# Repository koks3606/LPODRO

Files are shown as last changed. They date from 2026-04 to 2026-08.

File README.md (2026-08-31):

# LPODRO

  

**A cheap, highly automated, and compact machine for home production of PCBs and finished electronic circuits.**

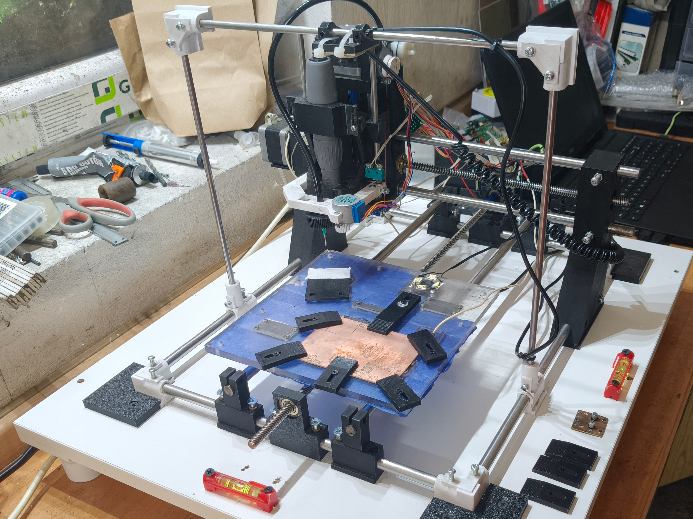
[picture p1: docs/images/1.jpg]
machine


LPODRO was designed with makers, hobbyists, amateurs, and small workshops in mind. It replaces chemical processes with precise milling of traces and holes, and its pick-and-place module automatically mounts SMD components onto the finished boards. A vision system automates calibration, inspection, and position correction of components. The project is open-source — anyone can build and modify the machine for rapid prototyping of their own circuits.

## Table of Contents

- [What it does](#what-it-does)

- [Current project status](#current-project-status)

- [Requirements](#requirements)

- [Repository structure](#repository-structure)

- [Getting started](#getting-started)

- [Machine construction](#machine-construction)

- [PnP head](#pnp-head)

- [Vision system](#vision-system)

- [Control electronics](#control-electronics)

- [Software](#software)

- [Automated circuit soldering (planned)](#automated-circuit-soldering-planned)

- [Roadmap / TODO](#roadmap--todo)

- [License](#license)

## What it does

At the core of LPODRO is a machine surrounded with a simple, automated workflow: the user supplies laminate and SMD components, and the machine carries out the successive stages of the process. The cameras determine the positions of the supplied materials and monitor every stage of production. A spindle precisely mills traces and mounting holes, eliminating the need for outdated and hazardous chemical PCB production processes and turning raw laminate into a functional PCB. The pick-and-place module then places the SMD components onto the board with high accuracy, and an integrated soldering module (to be added) will permanently bond the components to the board — so that with minimal effort and without needing extensive knowledge, the user ends up with a fully finished, working circuit.

## Current project status

> **The project is still a work in progress (WIP).**

At this point, LPODRO can reliably:

- mill single-layer PCBs,

- detect 0805 and bigger components,

- use them for automated assembly.

The 3D models, software, and other materials presented in this repository are not yet finished or fully polished. Proper documentation and many features are missing, there are known bugs and issues, and more are yet to be found.

At this point I'm not discouraging anyone to build LPODRO for yourself. Most of the features I plan to add will be done either through software or by adding stuff ontop of existing hardware. Even now LPODRO can be useful but with time it will be easier to build and have more functions. Note that right know you need some knowledge to work with LPODRO (look at [Requirements](#requirements))

## Requirements

Before starting a build, it helps to have:

- Basic knowledge of how CNC machines are built and operated — both mechanically and on the software side, later on this requirement will be removed through easier to use software.

- Basic knowledge and tools needed to solder, program MCUs and assemble hardware (cutting, grinding etc.).

## Repository structure

```
LPODRO/      
├── hardware/   STEP/STL files, schematics and technical drawings  
├── software/   Python script for the raspberry pi and main code alongside requirements.txt      
├── docs/       Assembly instructions, user manual and photos      
├── LICENSE      
└── README.md
```

## Getting started

Everything you need to get started is in the [assembly manual](docs/manuals/assembly%20manual.pdf).

## Machine construction

The mechanical construction of LPODRO is based on a frame made of steel rods joined with 3D-printed angle brackets. This solution allows for a simple and extremely cheap frame, which forms the basis of the entire machine — subsequent parts, such as motor mounts and axis holders, slide onto it. The drive system for the X, Y, and Z (spindle) axes is based on the classic mechanism of two guide rails and one T8 trapezoidal lead screw driven by a Nema17 stepper motor. The machine is equipped with two Z axes: the first moves the spindle, and the second — mounted on the spindle holder — operates the PnP head, allowing independent control of the spindle and the head and simplifying the mechanics.

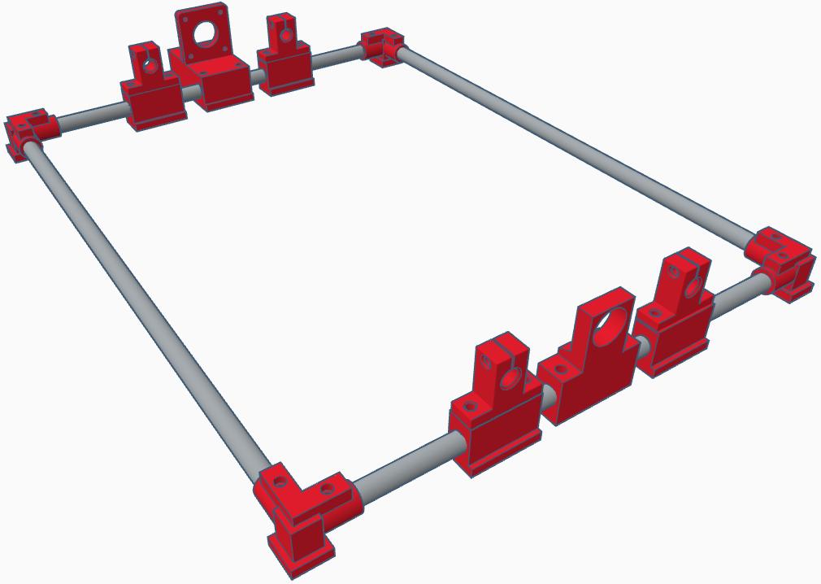
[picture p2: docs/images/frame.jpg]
frame


## PnP head

The PnP head was built from scratch for this project, using widely available and very cheap parts while retaining the functionality of commercially available equivalents. It features an easy needle-change mechanism, with needles widely available in a variety of sizes. It also has a built-in stepper motor that, working together with the vision system, rotates the picked-up components appropriately so that they land in the correct position on the PCB being produced. The head's motion system uses a non-standard, simple drive based on a wound string: the motor winds or unwinds the string, changing its effective length, which translates into the up-down movement of the head. This solution ensures low cost, simple construction, and high resistance to mechanical damage — in the event of a collision, the head will simply "bottom out" against the work surface instead of being damaged.

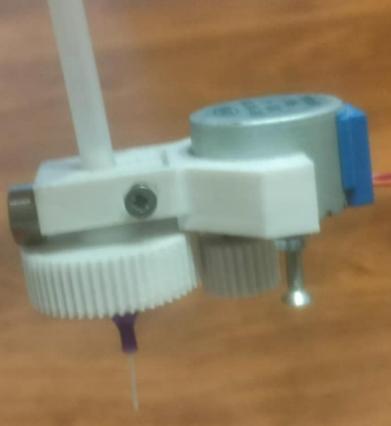
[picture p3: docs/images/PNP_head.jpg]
PNP HEAD


You can also check out the [demo](https://youtu.be/qNj2u1QFK_k).

## Vision system

A key element of the system is two cameras. A ceiling camera, positioned above the work surface, photographs the entire working area to locate the laminate, automatically determine the optimal zero point (minimizing material waste), and detect the positions of SMD components prepared by the user for mounting. A second camera is mounted flush with the work surface — the picked-up SMD component passes over the lens, and the vision system determines its orientation and offset relative to the PnP needle, allowing precise correction of rotation and position before placement. This is conceptually identical to industrial PnP equipment, but implemented in a cost-effective way.

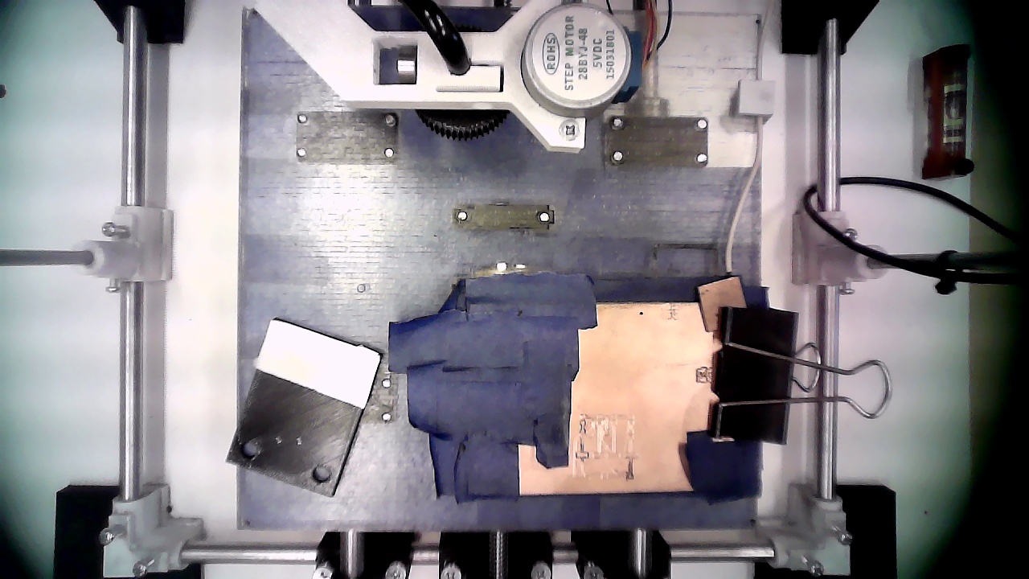
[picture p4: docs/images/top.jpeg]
top
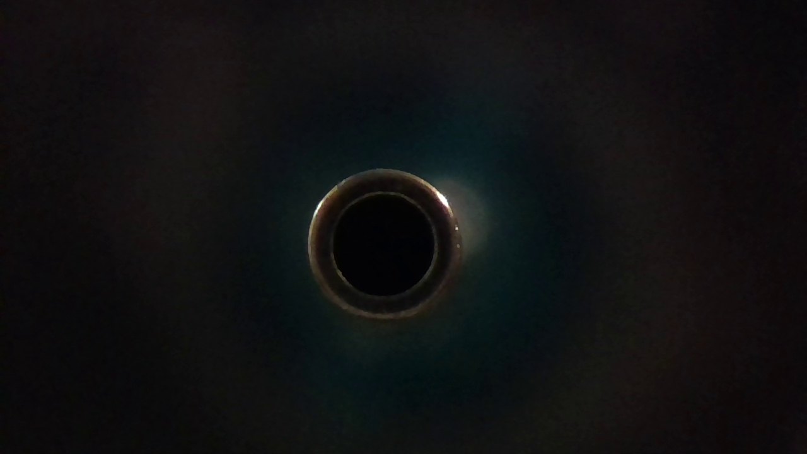
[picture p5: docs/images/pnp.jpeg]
pnp
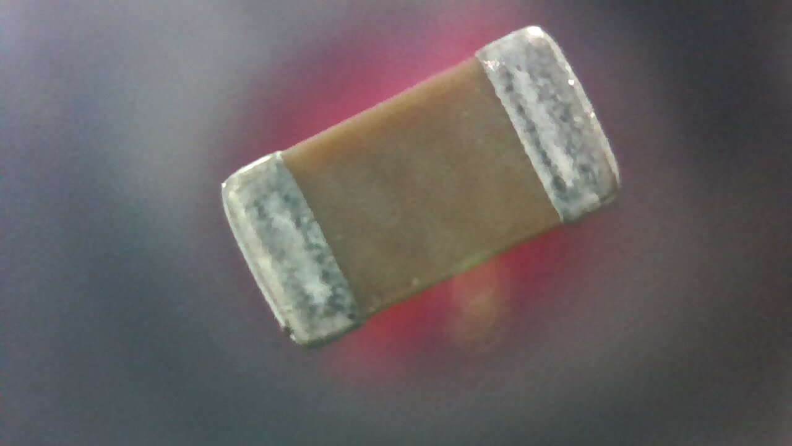
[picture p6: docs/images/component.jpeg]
component
  

## [Control electronics](hardware/schematics/Schematic.pdf).

The control electronics are based on widely available components: an Arduino Nano running GRBL firmware controls the X, Y, and Z axes using A4988 stepper drivers. A second system, a Raspberry Pi Zero W, currently controls the PnP head's stepper motors as well as the operation of the spindle, vacuum pump and LEDs. All other processes (G-code generation, auto-leveling, sending information to the machine, receiving the camera signal, etc.) currently run on a computer that must remain constantly connected to the machine. In the future, the Raspberry Pi will take over all these tasks, meaning that operating the machine will only require any device from which a PCB Gerber file and a PnP coordinate file can be sent — similar to modern 3D printers. To achieve this, the plan also includes adding a screen and buttons to the machine.

## Software

The software for LPODRO was written from scratch because available solutions (both commercial and open source) did not fully meet the required automation and usability goals. It's responsible for fully automating the process: auto-calibration, image analysis, milling toolpath generation, pick-and-place operation sequencing, position correction using camera data, and error handling and safety procedures. Currently, the user interface is CLI-based; a GUI overlay is planned for the future to significantly improve ease of use. Currently, the software supports importing popular PCB design formats, process parameterization, and job progress monitoring. All of the software is written in Python.

## Automated circuit soldering (planned)

The project plans to add an integrated heating plate to the machine, placed in the work surface. Once a board with solder paste applied is placed on it, the system will adjust the temperature profile and evenly heat the PCB to reflow temperature, enabling mass, repeatable bonding of SMD components without manual soldering of individual parts. This will significantly raise the level of automation and ergonomics, shortening operation time and reducing user interventions, and will allow the entire process of producing an electronic circuit — creating the PCB, placing components, and soldering them — to be closed within one device. Control of the heating profile (temperature sensor plus regulation) will ensure assembly safety and repeatable results across different boards and components.

## Roadmap / TODO

**Hardware**

- [ ] Improve the general experience with SMD components

- [ ] Add automated circuit soldering

- [ ] Add a way to make two-layer PCBs

- [ ] Try converting an old 3D printer into LPODRO

**Software**

- [ ] Add a way to generate stencil files (to either 3d print or mill)

- [ ] Move everything that runs on an addtional PC to the RPI

- [ ] Add a GUI to the software

**Documentation**

- [ ] Improve the manual

## License

This project is released under the [MIT License](LICENSE).

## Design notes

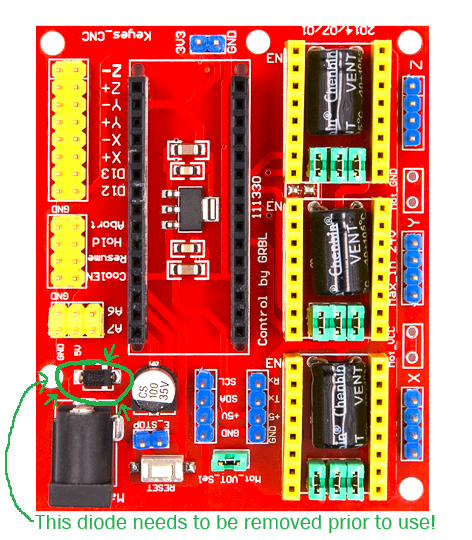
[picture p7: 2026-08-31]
hardware/schematics/Diode.png

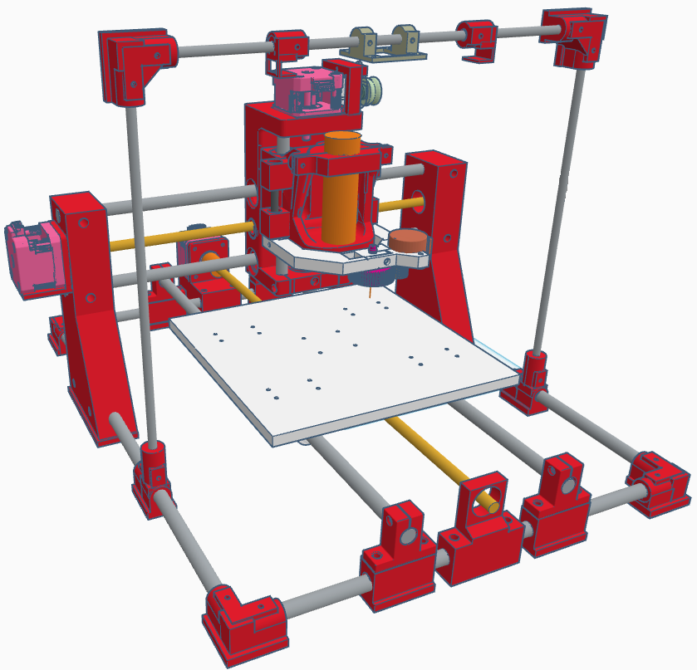
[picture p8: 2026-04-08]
hardware/STLs/3d visualization.png

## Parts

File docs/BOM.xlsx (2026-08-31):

Nb | name | quantity | notes | example link
1 | filament | ~1kg | do not use PLA! Use PETG or something stronger | link (https://allegro.pl/oferta/filament-sunlu-petg-black-czarny-1kg-1-75mm-18720979372)
2 | 10mm steel rod | 334cm | 2x 41cm and 2x 31.5cm for the frame, 2x 44cm for the y axis, 2x 36.5cm for the x axis and 2x 14cm for the z axis | buy localy
3 | 6mm steel rod | 121cm | 2x 28.5cm and 32cm for the camera frame and 2x 16cm for the second z axis
4 | 500mm T8 screw | 1 | can either have 2mm or 8mm pitch, can be cut down to 45cm to not stick out | link (https://abc-rc.pl/pl/products/sruba-trapezowa-t8x8-500mm-nakretka-z-brazu-thsl-500-8d-8606.html?query_id=1)
5 | 400mm T8 screw | 1 | can either have 2mm or 8mm pitch, can be cut down to 36.5cm to not stick out | link (https://abc-rc.pl/pl/products/sruba-trapezowa-t8x8-400mm-nakretka-z-brazu-thsl-400-8d-8605.html?query_id=1)
6 | 250mm T8 screw | 1 | can either have 2mm or 8mm pitch, needs to be cut down to 13cm to not stick out | link (https://abc-rc.pl/pl/products/sruba-trapezowa-t8x8-250mm-nakretka-z-brazu-thsl-300-8d-20284.html?query_id=1)
7 | sd card | 1 | at least 16gb | link (https://elektroniksc.com.pl/technika-komputerowa/karta-pamieci-micro-sd-hc-16gb-adapter-sd-goodram-66-240-rohs/)
8 | 685zz bearing | 1 |  | link (https://allegro.pl/oferta/685-zz-lozysko-wysokoobrotowe-5x11x5-mm-618-5-zz-2z-6521264095)
9 | 608zz bearings | 3 |  | link (https://abc-rc.pl/pl/products/lozysko-kulkowe-8x22x7-os-8mm-typ-608zz-8496.html?query_id=3)
10 | nema17 steppers | 3 | can be basically any nema17 motor, I used 17pm-k343cn03ca ones. New ones can be bought but they are VERY expensive for some odd reason. Check locally for used ones. | link (https://elektroniksc.com.pl/silniki-elektryczne-dc/silnik-dc-2-fazowy-krokowy-bipolarny-nema17-3-4v-dc-1-7a-krok-1-8-200-krokow-na-obrot-4-28kg-cm-0-42nm-wale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)
11 | 8mm to 5mm couplers | 3 | use the rigid ones, not the flexible ones used in, for example, 3d printers z axies | link (https://botland.com.pl/elementy-do-budowy-drukarek-3d/18933-sprzeglo-stale-aluminiowe-5x8mm-5904422355012.html)
12 | lm10uu bearings | 8 or 12 | the quantity depends on how many you will put in the z axis and spindle carraiges | link (https://abc-rc.pl/pl/products/lozysko-liniowe-lm10uu-10mm-reprap-3d-cnc-9734.html?query_id=13)
13 | lm6uu bearings | 4 |  | link (https://allegro.pl/oferta/lm-06-uu-lozysko-liniowe-na-walek-6mm-lm6uu-17576690130)
14 | T8 nuts | 6 | T8 screws often come bundled with at least one T8 nut. Buy nuts with the same pitch as the screws | link (https://abc-rc.pl/pl/products/nakretka-t8x8-z-brazu-do-sruby-trapezowej-4-zwoje-drukarka-3d-9275.html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)
15 | ov9726 camera | 1 | the bed camera, use with lens from the second camera | link (https://pl.aliexpress.com/item/1005003808666298.html)
16 | the second camera | 1 | this one doesnt really have any markings lol, use it with the bed camera lens | link (https://pl.aliexpress.com/item/1005004542714669.html)
17 | bed leds | 4 | can be any bright, white, smd leds. | link (https://elektroniksc.com.pl/diody-led-smd/dioda-led-e2-stw8q14d-smd-5630-biala-4000k-bialy-31-2lm-2-7-2-8v-65ma-120-seoul-semiconductor-s1w0-5630xx8003-000000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)
18 | the bed | 1 | Personally i ordered one from 8mm pmma but i would recommend making it out of 4mm steel | link (https://allegro.pl/oferta/blacha-stalowa-formatka-25x25-cm-stal-4mm-12075468236)
19 | 28byj-48 stepper | 2 |  | link (https://abc-rc.pl/pl/products/silnik-krokowy-28byj-48-z-przekladnia-5v-0-3a-0-03nm-arduino-6290.html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)
20 | 6x4mm tube | ~40cm | cut it down during assembly | link (https://abc-rc.pl/pl/products/wezyk-do-kroplownikow-4-6-mm-waz-kapilarny-pcv-do-nawadniania-mikrozraszaczy-17616.html)
21 | string | ~40cm | I just used some sewing string i stole from my mom
22 | Marathon sde-h37ln | 1 | this is the spindle itself, I personally used this exact model but on for example aliexpress there are cheaper alternatives, haven’t tried them tho | link (https://pl.aliexpress.com/item/1005007485295420.html)
23 | milling bits | a lot | you’ll most likely break a lot of bits during the early phase of using LPODRO. Marathon is a great spindle but it only can use bit that have a ~2mm handle. I bought this kit and it has 3 bits that can actually be used for milling pcbs. Buy at least 2 sets | link (https://pl.aliexpress.com/item/1005007243870497.html)
24 | vacuum pump | 1 | do note that this pump is a consumable – it will break over time, I recommend buying at least two | link (https://pl.aliexpress.com/item/1005008684218965.html)
25 | m3 screw | a lot | its best to buy a set of different lengths | buy localy
26 | m3 nuts | a lot
27 | Mains cable | 1 |  | link (https://elektroniksc.com.pl/kable-zasilajace-1/kabel-zasilajacy-wtyk-cee-7-7-prosty-przewody-16a-250v-1-8m-czarny-3-zyly-1-5mm2-pvc-okragly-linka-cu-lian-dung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)
28 | female DIN connector | 1 | Either a 3 or 5 pin can be used. If you are using a spindle other then the marathon one check if its using this connector | link (https://elektroniksc.com.pl/zlacza-din-i-glosnikowe/gniazdo-din-zenskie-5-pin-uklad-wypr-180-proste-lutowane-dc-102/)
29 | Theraded heat inserts | 38 |  | link (https://allegro.pl/oferta/mosiezna-wkladka-gwintowana-insert-niska-m3-x-4mm-100-szt-18782797301)
parts from the schematic
30 | uln2003 driver | 2 | do note that they have a tendency to randomly die. Buy at least 4 | link (https://abc-rc.pl/pl/products/modul-sterownika-uln2003-v2-do-silnikow-krokowych-arduino-6405.html?text=uln2003)
31 | Limit switches | 4 | i used a wk325 switches | link (https://elektroniksc.com.pl/mikroprzelaczniki-snap-action/mikroprzelacznik-wk325-dzwignia-13mm-1no-1nc-mini-1a-125v-ac-kw10-z2p150-msw-22-kls-rohs/)
32 | raspberry pi zero w | 1 |  | link
33 | Relay | 3 | 5v coil voltage, >24v contact voltage. Arduino relay modules can be used and that will eliminate the need for the whole relay circuitry | link (https://elektroniksc.com.pl/przekazniki-bistabilne/przekaznik-tq2-l2-5v-bistabilny-5v-dc-dpdt-2-styki-przelaczne-2-cewki-0-5a-125v-na-pcb-az850p2-5-panasonic-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) | link (https://elektroniksc.com.pl/moduly-przekaznikow/modul-rozszerzeniowy-4-przekaznik-5v-dc-z-separacja-optyczna-10a-250v-kolkowe-srubowy-4-kanaly-arduino-iot-diy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)
34 | Diode | 3 | Any diode can be used. It's used to discharge the negative voltage spike from the relay coils. For example 1N4007 can be used | link (https://elektroniksc.com.pl/diody-prostownicze/dioda-prostownicza-1a-1000v-1kv-do41-tht-1n4007-rohs-opakownaie-100szt/)
35 | NPN transistor | 3 | Used to drive the relay. 2N2222 can be used. | link (https://elektroniksc.com.pl/tranzystory-npn/tranzystor-2n2222-npn-0-6a-40v-625mw-250mhz-to92-tht-0743-ph2222a-pn2222-rohs-op-100szt/)
36 | Transistor resistor | 3 | The resistor on the transistor base. I used a 680ohm one | link (https://elektroniksc.com.pl/rezystory-0-125-0-5w/rezystor-weglowy-680ohm-0-25w-1-4w-5-0207-tht-cf1-4w-680r-rohs-opakowanie-100szt/)
37 | LED resistor | 1 | The resistor before the LEDS. Heavily depends on the type and amount of LEDs you choose. I used an 680ohm one | link (https://elektroniksc.com.pl/rezystory-0-125-0-5w/rezystor-weglowy-680ohm-0-25w-1-4w-5-0207-tht-cf1-4w-680r-rohs-opakowanie-100szt/)
38 | CNC shield v4 | 1 | Check this out as this is very important (https://www.instructables.com/Fix-Cloned-Arduino-NANO-CNC-Shield/) | link (https://abc-rc.pl/pl/products/modul-do-grawerowania-cnc-v4-shield-do-arduino-nano-9470.html)
39 | 24v psu | 1 | i used a 150w one. You may want to calculate the power on your own based on the steppers you chose | link (https://allegro.pl/oferta/zasilacz-do-tasm-led-24v-dc-6a-150w-slim-modulowy-transformator-montazowy-13380444696)
40 | 12v source | 1 | I used a small 230vac to 12vdc psu. A step down buck can be used but then you may need to use a more powerful 24psu | link (https://elektroniksc.com.pl/moduly-przetwornic/przetwornica-step-down-ac-dc-csc7203-uwej-230v-uwyj-12v-prad-1a-12w-43x25mm-a-pn-1a-dc-jh/)
41 | 5v source | 1 | I used a small 230vac to 5vdc psu. A step down buck can be used but then you may need to use a more powerful 24psu | link (https://elektroniksc.com.pl/przetwornice-regulatory/przetwornica-step-down-ac-dc-uwej-230v-uwyj-5v-prad-2a-10w-43x25mm-a-pn-10w-jh/)
42 | alligator clip | 1 | This is the probe that is placed on the mill when probing the z height and doing the autoleveling | link (https://elektroniksc.com.pl/krokodylki-pomiarowe/krokodylek-izolowany-41-5mm-czerwony-nh041-zaciskany-stal-niklowana-27-711-1-amass-rohs-opakowanie-100szt/)
3d printed parts
43 | Gear 1 | 1
44 | gear 2 | 1
45 | Y axis rod holder | 4
46 | Second Z axis spool | 1
47 | PnP head frame | 1
48 | X axis pillar 1 | 1
49 | X axis pillar 2 | 1
50 | Spindle clamp | 1
51 | Bed bearings | 4
52 | Y axis bearing holder | 1
53 | Bed nut 1 | 1
54 | Bed nut 2 | 1
55 | Second Z axis stepeper holder | 1
56 | Z axis carriage | 1
57 | Camera frame connector | 2
58 | Y axis stepper holder | 1
59 | angle connector | 6
60 | Spindle carriage | 1 | either the completed one or not, if not also print the second Z axis bearing holders
61 | Camera holder | 1 | either the camera holder itself or phone holder 1 and 2 if you are using a phone
62 | pcb holder | depends | depends on how big laimantes you're going to mill

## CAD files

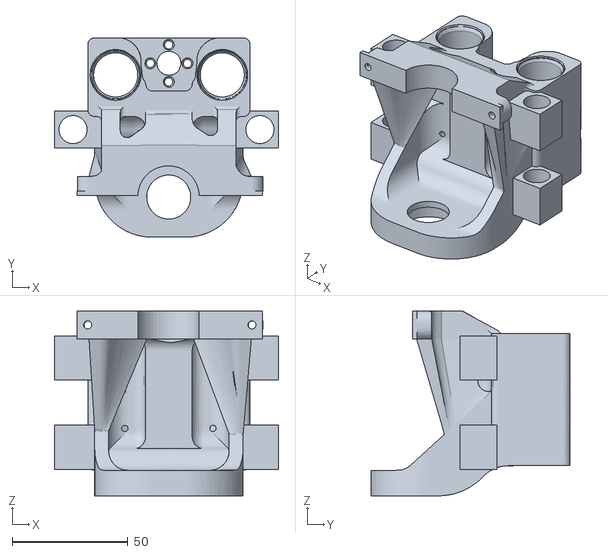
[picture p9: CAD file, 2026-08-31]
hardware/STLs/complete spindle carriage.stl
96.6 x 86.0 x 79.6

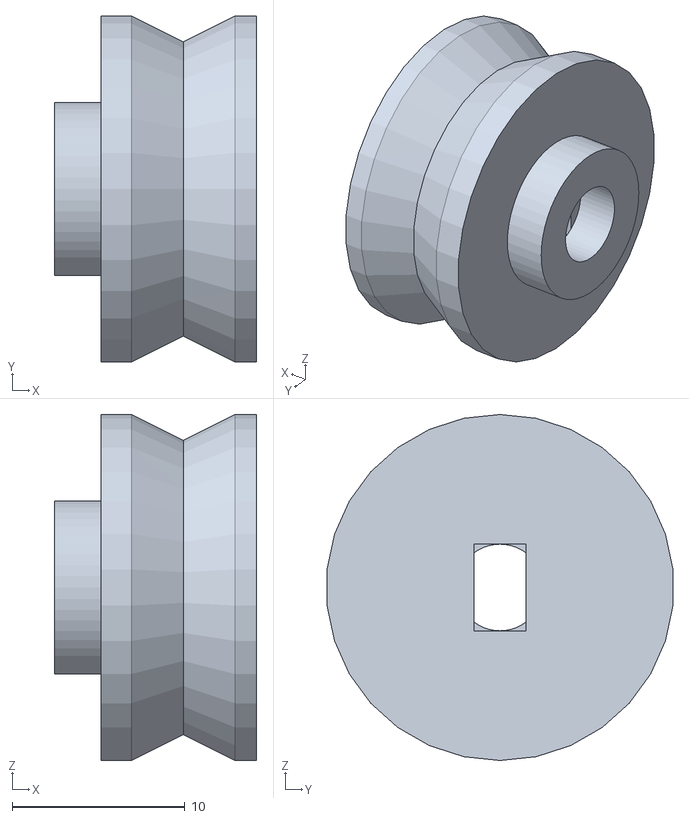
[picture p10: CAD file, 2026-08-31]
hardware/STLs/second Z axis spool.stl
11.7 x 20.0 x 20.0

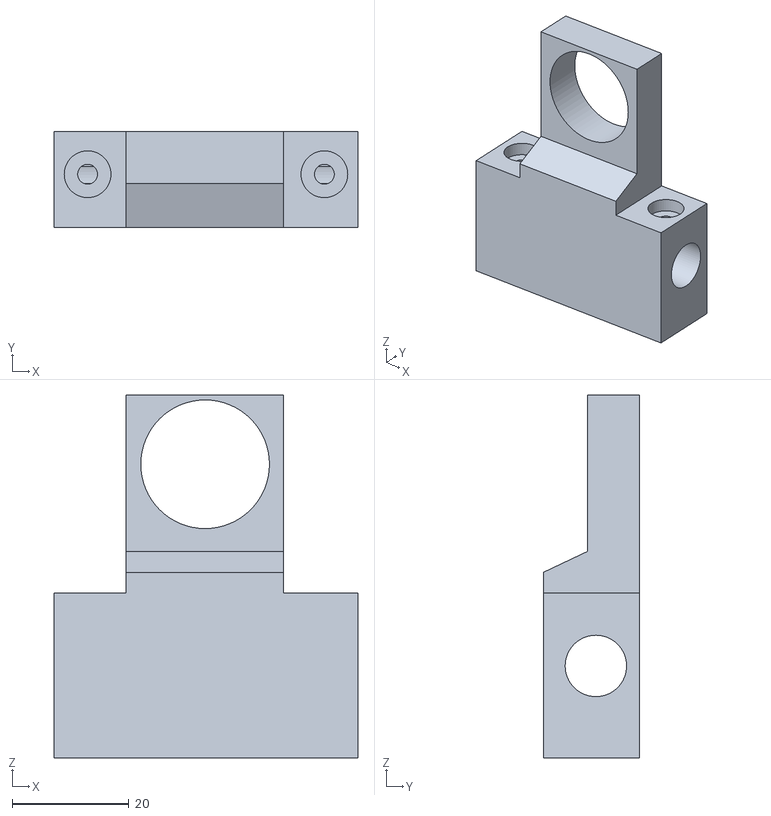
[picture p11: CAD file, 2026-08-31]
hardware/STLs/Y axis bearing holder.stl
52.0 x 16.5 x 62.1

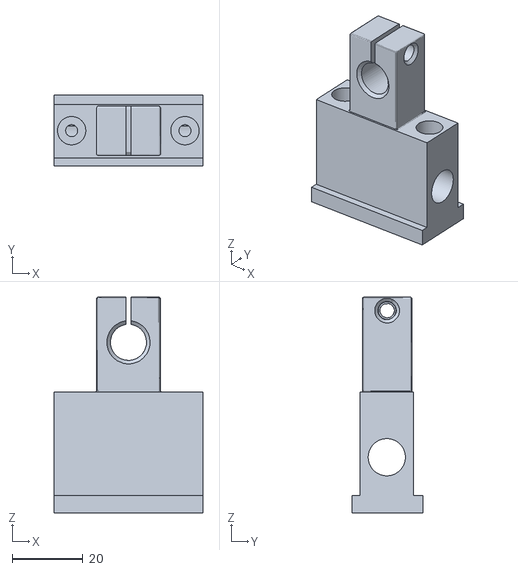
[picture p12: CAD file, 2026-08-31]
hardware/STLs/Y axis rod holder.stl
42.0 x 20.0 x 61.0

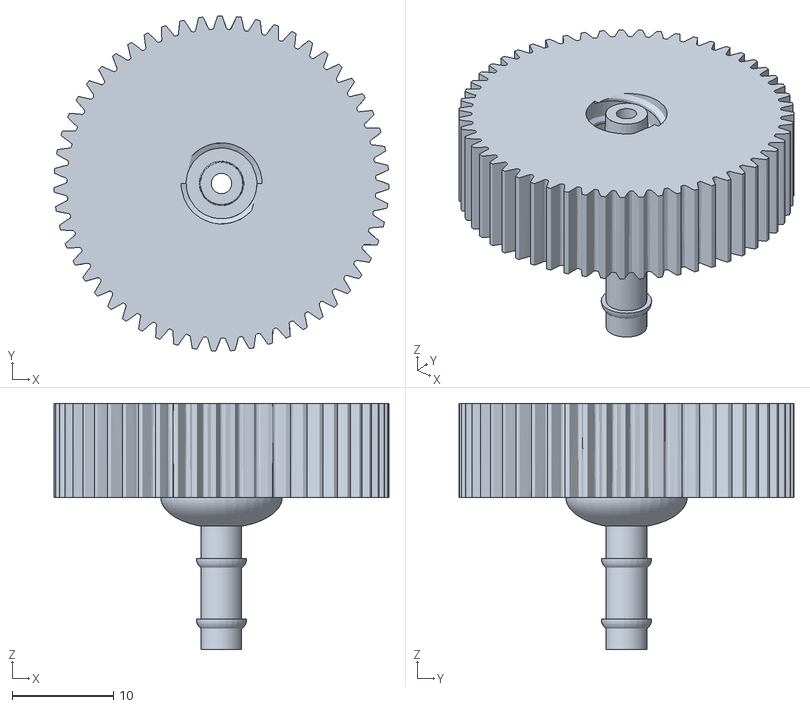
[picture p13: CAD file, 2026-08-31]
hardware/STLs/gear 1.stl
33.1 x 33.0 x 24.3

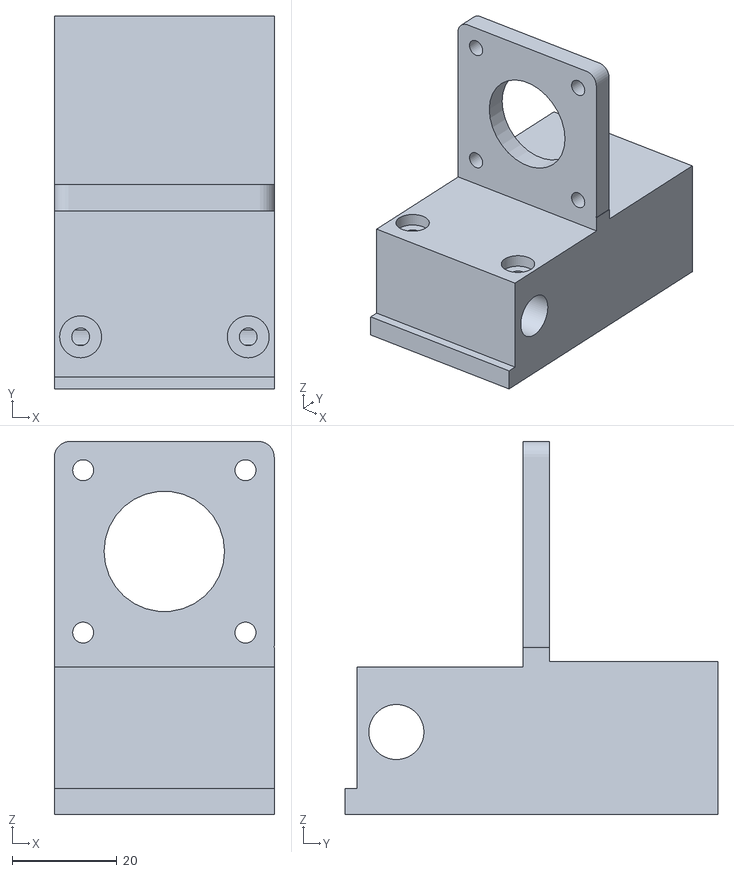
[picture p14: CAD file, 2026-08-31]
hardware/STLs/Y axis stepper holder.stl
42.1 x 71.2 x 71.2

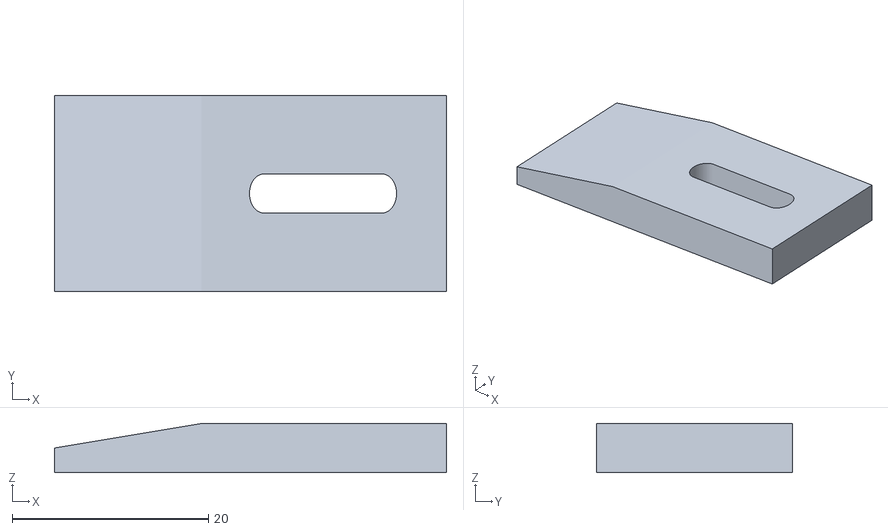
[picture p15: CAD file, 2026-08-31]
hardware/STLs/pcb holder.stl
40.0 x 20.0 x 5.00

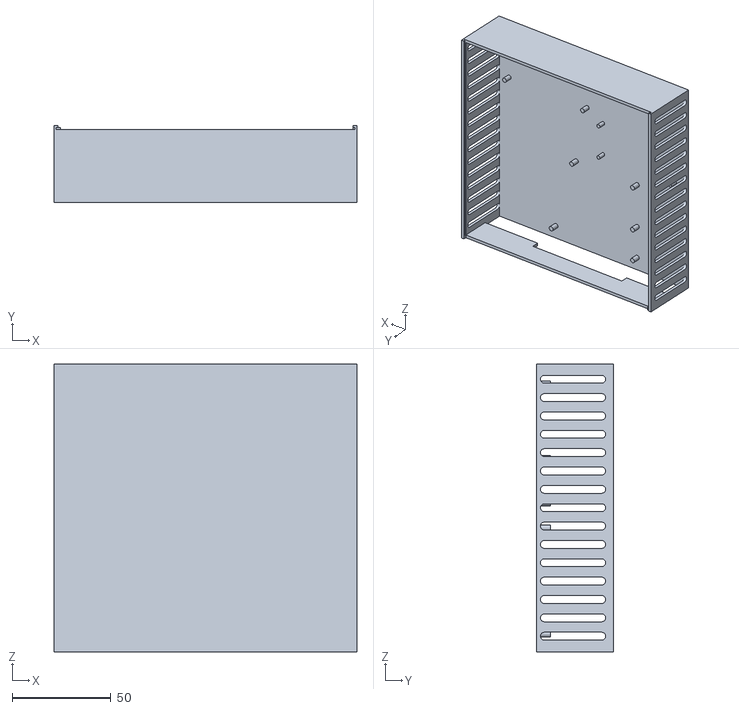
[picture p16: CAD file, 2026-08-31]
hardware/STLs/case.stl
153.3 x 39.0 x 145.7

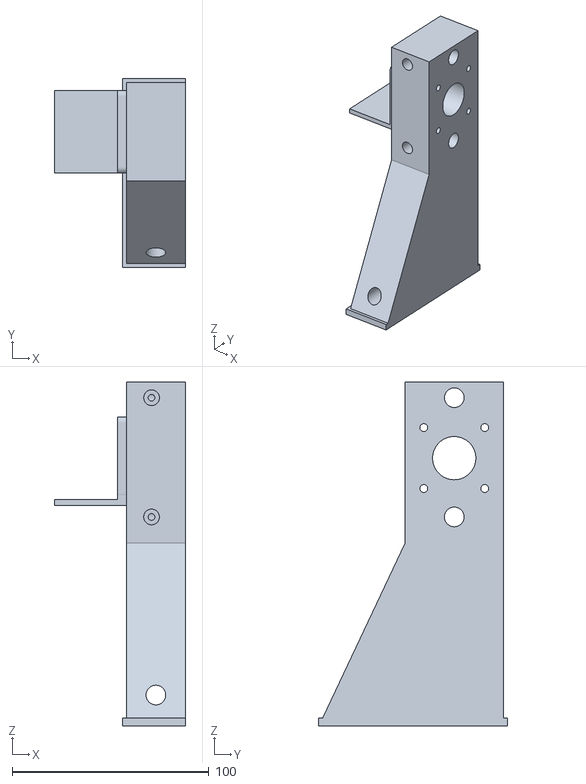
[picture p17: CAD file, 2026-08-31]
hardware/STLs/X axis pillar 1.stl
66.7 x 96.0 x 175.0

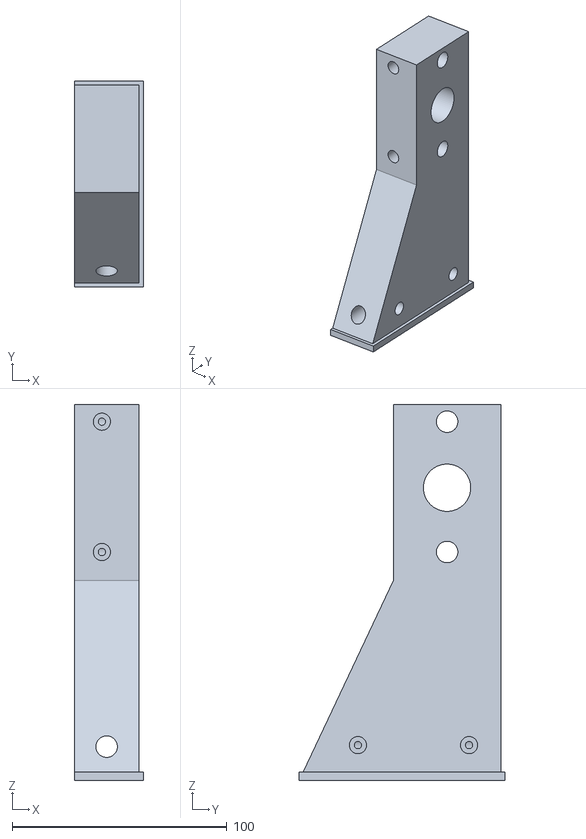
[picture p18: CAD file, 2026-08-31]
hardware/STLs/X axis pillar 2.stl
32.0 x 96.0 x 175.0

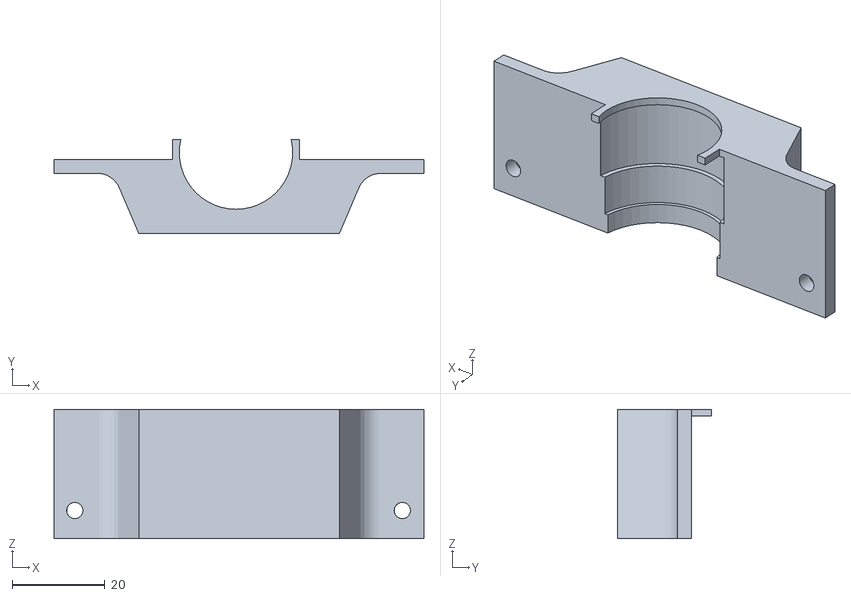
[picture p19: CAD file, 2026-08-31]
hardware/STLs/spindle clamp.stl
80.0 x 20.4 x 28.0

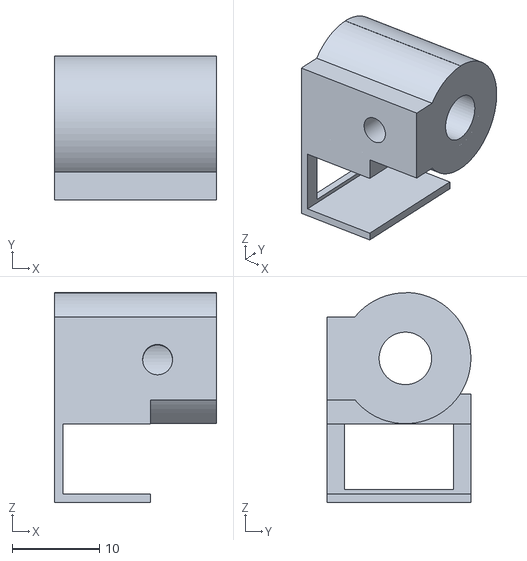
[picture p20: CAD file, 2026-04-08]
hardware/STLs/phone holder 1.stl
18.5 x 16.5 x 24.0

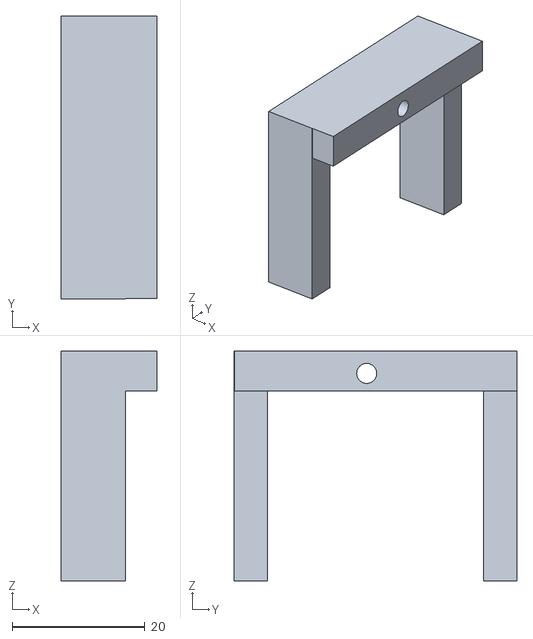
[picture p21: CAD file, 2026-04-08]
hardware/STLs/second Z axis stepper holder.stl
14.4 x 42.6 x 34.6

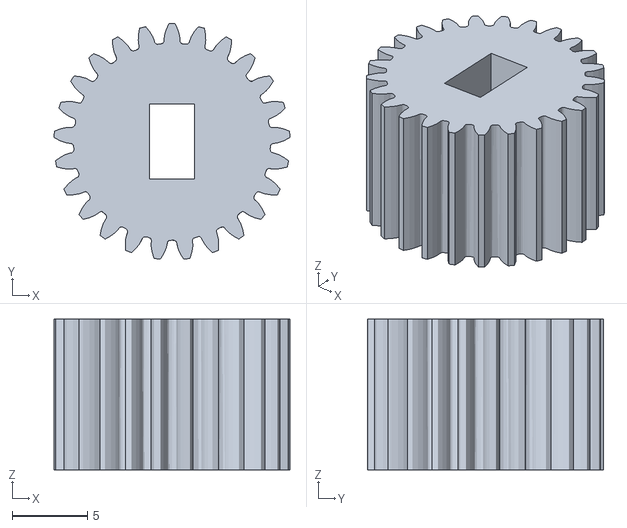
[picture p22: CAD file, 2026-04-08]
hardware/STLs/Gear 2.stl
15.6 x 15.6 x 10.0

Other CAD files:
hardware/drawings/bed.FCStd
hardware/STLs/spindle carriage.stl
hardware/STLs/angle connector.stl
hardware/STLs/camera holder.stl
hardware/STLs/PnP head frame.stl
hardware/STLs/Z axies carriage.stl
hardware/STLs/bed bearing.stl
hardware/STLs/bed nut 1.stl
hardware/STLs/bed nut 2.stl
hardware/STLs/camera frame connector.stl
hardware/STLs/phone holder 2.stl
hardware/STLs/second Z axis bearing holders.stl

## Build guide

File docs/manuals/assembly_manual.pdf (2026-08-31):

# About This Manual

In this manual I’d like to create a step-by-step tutorial that will guide you through building your own LPODRO machine.
This is the first version of this manual that is still a WIP. In the future I’d like it to be in a easy to read form, with a lot of pictures that will show what exactly you need to do. I also plan to record a video tutorial to further simplify the building process.
As of right now the current state of this manual is more like an info dump by me – sharing everything I learned over the past 3 years while working on this project. Most likely I will skip or forget something here, that's why in the readme file it says that you need to have at least some knowledge of how CNC machines are built. At this point it is more than likely that you will need to figure out some stuff out on your own.

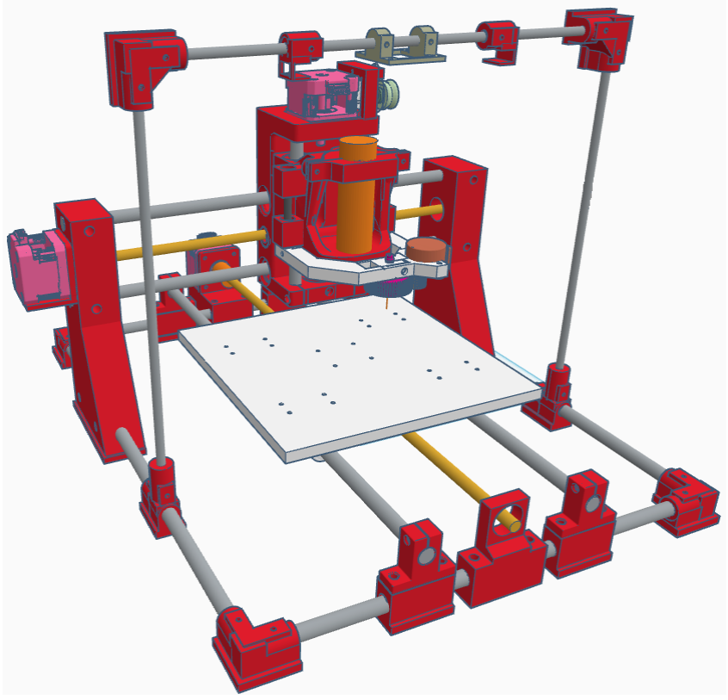
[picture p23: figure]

This is the visualization picture. While following this manual keep in mind that this ^ is what you are building. Each step will get you closer to having this machine. After each step check if whatever you did looks like what is on this picture. If not you most likely did something wrong.

# Frame Assembly

Step 1: Cut the rods to length
To start out the building process you need to cut the 10mm rod into the proper lengths: 2x 41cm and 2x 31.5cm for the main frame, 2x 44cm for the y axis, 2x 36.5cm for the x axis and 2x 14cm for the z axis. For this I used an angle grinder. I also used it to round out the rough edges. Be aware that the rods will get very hot – don’t touch them and don’t put them into the 3d printed parts right after cutting them.

Step 2: Check the 3D printed parts fit the rods
After cutting the rod, take the ones that will be used for building the main frame alongside 4 angle connectors, both X axis pillars, 4 Y axis rod holders, Y axis bearing holder, Y axis stepper holder and 2 camera frame holders. Take the 3d printed parts and check if the hole that the rods will go into have the proper diameter. To do so take a rod and try inserting it into the hole. There shouldn’t be to much resistance (if you put too much pressure the part will just split open on the layer lines) but also the rod cannot be extremely loose. It should go in with just a bit of pressure and have a bit of give in each direction. If it doesn’t either drill the hole out to a proper size or file it down. Now you need to make a choice because you can either put threaded inserts into the 3d printed parts or screw a screw right into it. Personally I did the latter because it’s much simpler and it’s strong enough for what you’re doing here. But if you insist on using threaded inserts the tip I can give you is after melting it in wait a bit to let the molten plastic harden. When it does take something thin, that can be inserted into the threaded insert without touching the threads, put it as far as you can and hit it pretty hard with your hand or a hammer. This will break out the plastic that has molten into the part that the rod will go into. If you don’t do this you won’t be able to screw the screw or put the rod in. If you choose to screw into the parts you need to do this at least once before putting the rod in.
Step 3: Insert the rods into the connectors
Next, take the two shorter rods, insert the Y axis rod holder, Y axis bearing holder and again a Y axis rod holder onto the first and and Y axis rod holder, Y axis stepper holder and again a Y axis rod holder on the second one. Insert each of the X axis pillars and camera frame connectors onto the longer rods.
Step 4: Form and square the main frame
After that insert the prepared rods into the angle connectors to form the main frame with inserted components in such a way that each part is orientated as shown on the visualization picture.
If what you have looks similarly to the visualization picture take 8 screws and put them into the angle connectors in such a way that they won’t fall out but wont stop the rod from moving freely in the connectors. Now you need to tighten the screws but also at the same time make sure that the rods form a right angle with each other to get a square frame. To do so you need to grab a machinist's square, put it in such a way that one of it arms goes parallel to one rod and the second one with a second and when the rods form a right angle tighten the screw. Repeat this process for all corners.

# Bed Assembly

Step 5: Prepare the bed plate and nut holders
With that done the next step is preparing the bed. Personally I ordered it to be cut out from PMMA but if not for the fact that I already had a PMMA sheet lying around that would have been very expensive. What I recommend doing is to buy a 25x25cm, 4mm thick steel sheet, drill the holes and make the camera cutout according to the bed.svg drawing and tap the holes with an m3 thread. Next take 4 bed bearing holders and both nut holders. Take the first T8 nut and screw it completely into the holder with holes. The second T8 nut goes into the holder with slots, put the 4 screws in, screw the m3 nuts onto them but don't tighten them – the nut needs to turn freely for now. Next take the bearings and push them into the holders. It should require a lot of force so they don’t fall out during normal operation but if you see any cracks forming on the holders during this step, replace the cracked part with a new one and file everything down a bit. After inserting the bearings make sure that one side is absolutely flush with its holder. It cannot be crooked or anything like that.
Important: Pay EXTRA attention to the bearings being flush with their holders – I wasted literal days trying to fix my machine only to find out I installed one of the bearings at an angle.

With that finished, take the bed and the prepared holders and screw them together. Make sure that the screws don’t poke out on the other side of the bed. If they do, add a nut or a washer to the screws.

Step 6: Mount the bed camera
As the last step take the bed camera (the ov9726 one with the lens from the second one), place it under the bed so that the lens points up and screw it in from the top.
Checkpoint: You should have a fully assembled bed with one loose T8 nut.

# Y Axis Assembly

Step 7: Prepare the Y axis stepper motor and bearing
Now you can take the Y axis stepper motor, a coupler and a T8 screw. Put the coupler onto the motor shaft and screw it in in such a way that one of the coupler screws pushes onto the flat part of the shaft. Next take the T8 screw, put it in the coupler and slowly tighten one of the coupler screws while rotating the T8 screw – the goal of this is to screw the coupler screw into the thread of the T8 screw. You will feel it when you hit the right spot. When you do it, tighten that coupler screw fully and then the second one and put this contraption aside. Now take the 608zz bearing and install it into the Y axis bearing holder.
Step 8: Slide the bed onto the Y axis rods
After that take the Y axis rods and put them through the first holder but not the second – leave the ends of the rods floating approximately in the middle, then with one hand hold the ends of the rods that are outside the main frame and with the second one pick up the bed and slide it onto the rods so that it will be inside the main frame. After that slide the rods fully in so that they go into the second rod holders.
Checkpoint: You should have the main frame with a bed that can freely slide back and forth and be moved on the frame.
Step 9: Install the Y axis motor and center the bed
Now take the stepper motor with the T8 screw, put the screw through the Y axis motor mount and push it until the screws tip touches the first nut. When it does start turning the screw so that it screws into the first nut. Do it until the tip of the T8 screw reaches the second, loose nut. When it does you’ll most likely need to turn the nut a bit to let the screw screw into it. When it does turn the screw until the stepper motor touches the Y axis motor mount and the tip of the T8 screw goes through the Y axis bearing. With that done you can screw the motor to its mount and tighten the rod mounts. After that we need to make sure that the bed is centered before screwing all of its mounts to the frame. To do so turn the T8 screw manually until the bed reaches one of the ends of the frame, then take some sort of measuring device and measure the distance between the rod holders and the frame rods. If the distances are not equal, move the holders a bit and repeat the process until they are. When they are equal, tighten the screw on the two holders on the side on which the bed is, then move the middle component (either the bearing or the stepper mount) and see if it springs back to a certain place (should be the middle between both rod holders), if it does, screw it in, if it doesn’t manually place it in the middle and then screw it in. After that manually move the bed to the other side and repeat this process. After that's done make sure that when rotating the T8 screw manually the resistance you feel is equal along the whole length. If it doesn’t it means that something isn’t parallel to each other. Check the rod holder, stepper and bearing mounts distance to each other and the frame and also if the rods and the T8 screw you installed isn’t bend. Now you need to properly tighten the loose T8 nut. What you are trying to achieve is to eliminate any play in the bed movement without adding any additional resistance for the stepper motor. To do so, grab both sides of the bed with your hands and try moving it left and right (in the direction of the rods and T8 screw). The nut should be held tight in its holder that it shouldn't move on its own. If you feel a bit of give caused by improper thread spacing (what we are trying to eliminate right now), and not because something else is moving (the frame, stepper mount, the loose nut in its holder etc), turn the nut a bit and try again. When the give stops try manually turning the T8 screw. If you feel a lot of additional resistance it means that you turned the nut too much. Now you need to find an angle where the bed doesn’t have any give but also when turning the T8 screw you don’t feel any additional resistance.

When you find this point screw the 4 screw on the nut all the way in.

### Checkpoint: You should have the main frame with a bed that should smoothly move back and

forth when rotating the T8 screw but should not move at all in any direction when pushing on the bed itself.

# PnP Head Assembly

Step 10: Assemble the PnP head
Now you are going to assemble the PnP head as it will make the next step easier. To do so take the PnP head frame, gear 1 and gear 2. Then insert 3 m3 nuts into the PnP head frame - two in the designated cuts next to the rod holes and one in the cut next to the gear 1 hole. Next take the 28byj-48 stepper motor and push the gear 2 onto its shaft. After that put it in the PnP head frame and screw it in. Next take the bearing and push it onto its place. With that done push the clear tube through the top of the PnP head frame. From the bottom push the gear 1 into the tube and then pull the tube back so that the part of the gear 1 that is in it goes through the hole of the PnP head frame. With that placed correctly take an m3 screw and screw it in the hole next to the gear 1. Tighten it until the tube and gear 1 connection is airtight but don’t over do it so that the stepper motor can still rotate the gear 1. Next take the properly cut rods, insert them into the their holes, make sure they form right angles with the PnP head frame and tighten the screws.

# Spindle Carriage Assembly

Step 11: Glue the Z axis bearing holders (if using the standalone carriage)
Now you’re going to assemble the spindle carriage. To do so you can either use the stand alone spindle carriage and glue the Z axis bearing holders onto it or the complete spindle carriage. Personally I chose the first option because it was simpler to print and more forgiving on my not so good 3d printer tolerances. But what you choose is completely up to you - the complete carriage has the advantage of not needing any gluing. If you choose to glue the bearing holders onto the carriage the PnP head that you just assembled is going to help you. To do it push the bearings into the holders (remember, they need to be PERFECTLY flush!) then slide them onto the rods of the PnP head, then apply a bit of super glue onto the contact area of the bearing holders and slide them into the proper height. You need to do bearings from both sides at the same time. While doing so make sure that the rod goes parallel with the spindle carriage and that it’s not crooked. When the glue dries a bit you can glue the remaining two bearing holders.
Step 12: Install bearings, T8 nut, and fit the spindle
Next take the spindle carriage (either the complete one or the glued one) and push 2 or 4 bearings into the bearing holes (once again its VERY IMPORTANT that they are COMPLETELY flat). I recommend using 4 for better stability and longevity. Next push one T8 nut and screw it in completely on one side and on the other side do the same eliminating the play trick you used on the bed. The last step with the spindle carriage is to sand down the part that actually touches the spindle. To do so take the spindle clamp and the spindle itself. Unscrew the top cap of the spindle and push the spindle clamp onto it then screw the cap back on. Then put the spindle with the clamp into the carriage and screw the two screws completely in. From the front the spindle should go completely down, if its at an angle somethings really wrong - most likely the 3d print quality is bad (take note of that as this can cause A LOT of different problems). From the side tho it will most likely be at an angle - that is to be expected. If it is look from the top, maybe shine a light from the bottom. You’re trying to see what parts actually touch the spindle. When you do find them take the spindle out, sand those parts a bit, put the spindle back in and check from the side if it points straight down. If it doesn't repeat this process until it does.
Checkpoint: When it finally does, congrats – you have a finished spindle carriage.

# Z Axis and X Axis Assembly

Step 13: Build the Z axis carriage
With the finished spindle carriage we can assemble the X axis. To do so take the Z axis carriage and the second Z axis stepper holder and spool. Insert either 2 or 4 bearings into the Z axis carriage (once again they need to be PERFECTLY flush and straight) and two T8 nuts and do the eliminating the play thing - just like with the spindle carriage. Next push a bearing into the bottom part of the Z axis carriage. Next take a Nema17 stepper motor and install a coupler and a T8 screw just like you did with the Y axis. Then insert it through the top of the z axis carriage until the tip of the T8 screw goes into the bearing. The face of the nema17 has to be flush with its designated place on the z axis carriage. If it isn’t because the T8 screw is slightly longer you can drill a hole under the bearing but be aware that the T8 screw cant poke under the Z axis carriage. If the motor sits flush with the z axis carriage and the T8 screw doesn’t stick out of the bottom you can slightly rise the nema17 until you can put the spindle carriage under the tip of the T8 screw. Next screw the screw into the spindle carriage. With that done screw the nema 17 into the Z axis carriage. Next push two rods in and make sure they go into the holes on the top of the Z axis carriage. After that make sure that they don't poke out from the bottom. If they don’t you can screw an m3 screw into their designated spots (no nut here, it screws into the 3d print itself). That should lock the rods in place.
Step 14: Attach the second Z axis stepper, pump, and string spool

The next step would be to glue the second Z axis stepper holder and the onto the top the Z axis car-

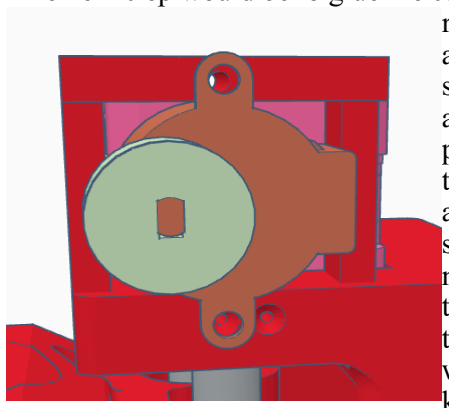
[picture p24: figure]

riage. To do so take a 28byj-48 stepper and push the second Z axis spool onto its shaft. Then insert the motor into the holder as shown on the picture, screw it together, place it on top of the z axis carriage and screw the second screw to it. With that done put some super glue along side the edge of the connection between the Z axis carriage and the second Z axis stepper holder and let it dry. To glue to pump in place just place it where it should be and put a lot of hotglue there. When it dries off connect the tube from the PnP head to the pump. To finish everything off take a piece of string, put a small dab of super glue in the middle of the spool, put the end of the string into that dab, wait for it to dry, when it does spool some string onto it, then take the string down and cut it so that it can reach to the bottom position of the pnp head (if the pnp head isn't inserted into the spindle holder that's a good time to do it). Then tie that end of the string onto the screw that is tightening the rod that's closer to the spooled stepper to the pnp head frame. With that done turn the spooled stepper so that the pnp head goes as far as it can, take a limit switch, push it into the pnp head until it clicks, then push it a bit more and glue it to one of the second Z axis bottom bearing holders.
Checkpoint: You should have a complete carriage that holds the spindle, PnP head and the pressure pump that will now go onto the X axis.
Step 15: Mount the assembly onto the X axis
To do so take a properly cut rod, insert it partially into the top hole of one of the X axis pillars and push it in until the tip reaches about half way. Then push the X axis assembly onto it and push the rod in until it goes into the hole of the second X axis pillar. Then push the second rod all the way through, assemble another nema17, coupler, T8 screw combo and push the T8 screw through the nema17 hole until its tip reaches the first nut, then screw it in completely and when the nema17 sits flush with the pillar screw it in. Lastly insert the 608zz bearing into the second x axis pillar, the one that houses the T8 screw tip
Step 16: Verify the mechanical assembly

With that done you should have an almost complete LPODRO machine. The only things that are missing are the camera assembly, the camera itself and the limit switches. Before we can go further you need to check if everything that you have build so far is correct. Check if it looks like in the visualization picture, check every angle you can imagine (if all of the frame corners are right angles, does the X pillars form right angles etc.), check if while moving the X, Y or Z axis manually you don’t encounter extra resistance somewhere along its movement path, check if during the assembly any screw didn’t come loose.

# Camera Frame Assembly

Step 17: Build and align the camera frame
If everything checks out you can assemble the camera frame. To do so take two angle connector and a proper camera holder - either camera holder or phone holder 1 and 2. If you use the normal camera holder this is a good time to screw the camera into it. Next take the rod, slide the camera connectors onto it and at each end of that rod place the angle connectors. Next place the properly cut rods into the camera frame connector and insert into those rods that angle connectors with the rod and camera holder. Now you should have a camera frame but it still needs to be properly placed, to do so move the bed into the proper position (the best way to do this is through the calibration menu from the python program but to use that you need to first complete this guide and then come back to this step), and move the whole camera assembly until the you see the whole bed on the camera feed. With that done you can screw/tighten all the screw while checking for right angles in the whole frame.

# Limit Switches

Step 18: Install the limit switches
Now the last remaining step is to install the limit switches. Right now I don’t have a way to screw them in or something - I just glued them. To do that correctly move for the axis (so the bed, z axis carriage or the spindle carriage) the the minimal position it can go to (looking from the front the bed has to go to the back, the z axis carriage to the left and spindle carriage to the top), then push a switch up against it until it clicks, then push it a bit more and then glue it in place - the exact same process as with the pnp head.
Checkpoint: This was the last step of the mechanical assembly of LPODRO. At this point you should have something that looks exactly like on the visualization photo.

# Electrical Assembly

What you need to do now is the electrical assembly (it mainly consists of just connecting cables to different places). What I can only say here is that everything that's needed is on the schematic, the example values can be found in the BOM, make sure that your cnc shield is not a cheap clone because if it is there is most likely a mistake in it - google cnc shield v4 fix.

### Important – remove the diode from the CNC shield: If you won’t you won’t be able to power

the stepper motors with 24v and you will have to use 12v instead. Also it improves safety. If you're not interested as to why, just skip to the next section. If you are, here you go: that diode connects the DC jack on the CNC shield to the VIN pin on the Arduino Nano. This means that the Arduino is powered more from the 12v than from the USB cable. This is a problem because if you short out the Arduino Nano (which is surprisingly easy) you will, best case scenario, blow out the 5v regulator on the Arduino Nano – but in my experience that happened only once out of 6 times. The first 2 shorts caused the atmega chip to fry itself, the third time damaged the 5v regulator but in a really weird way, because if it would have been powered with up to 10v everything would work perfectly fine, but if that regulator would get anything higher than 10v (which is what it would get if that diode had not been removed) the Arduino would go absolutely bananas. The next 2 shorts caused partial damage to the atmega chip and the last time fried the diode that's on the Arduino Nano. If you remove the diode from the CNC shield, the Arduino Nano will need to be powered from USB. And that is good, because the USB port on laptops but also on the Raspberry Pi Zero W has a 500mA resettable fuse, so if you short something out now the Arduino will lose power long before any permanent damage can occur. Also by removing this diode you remove the only 12v part from this line and this allows for the use of 24v which allows to run the steppers at a higher torque.

After the electrical assembly the last step of this manual is the first configuration - stuff you need to do only once.

# GRBL Configuration

Step 19: Flash the Arduino Nano with GRBL
First order of business would be to flash the Arduino Nano with GRBL. This is a good tutorial: https://www.instructables.com/How-to-Installuse-GRBL-With-Your-Cnc-Machine/ – just don’t use the Prusa steps calculator. Instead, for the whole config, use these values:
$0 = 10 (Step pulse time, microseconds)
$1 = 255 (Step idle delay, milliseconds)
$2 = 0 (Step pulse invert, mask)
$3 = 4 (Step direction invert, mask)
$4 = 0 (Invert step enable pin, boolean) $5 = 1 (Invert limit pins, boolean)
$6 = 0 (Invert probe pin, boolean)
$10 = 1 (Status report options, mask)
$11 = 0.010 (Junction deviation, millimeters) $12 = 0.002 (Arc tolerance, millimeters) $13 = 0 (Report in inches, boolean)
$20 = 0 (Soft limits enable, boolean)
$21 = 1 (Hard limits enable, boolean)
$22 = 1 (Homing cycle enable, boolean)
$23 = 3 (Homing direction invert, mask)
$24 = 50.000 (Homing locate feed rate, mm/min)
$25 = 500.000 (Homing search seek rate, mm/min)
$26 = 250 (Homing switch debounce delay, milliseconds) $27 = 3.000 (Homing switch pull-off distance, millimeters) $30 = 1000 (Maximum spindle speed, RPM)
$31 = 0 (Minimum spindle speed, RPM)
$32 = 0 (Laser-mode enable, boolean)
$100 = 400.000 (X-axis travel resolution, step/mm) $101 = 400.000 (Y-axis travel resolution, step/mm) $102 = 400.000 (Z-axis travel resolution, step/mm) $110 = 500.000 (X-axis maximum rate, mm/min) $111 = 500.000 (Y-axis maximum rate, mm/min) $112 = 50.000 (Z-axis maximum rate, mm/min) $120 = 800.000 (X-axis acceleration, mm/sec^2) $121 = 800.000 (Y-axis acceleration, mm/sec^2) $122 = 100.000 (Z-axis acceleration, mm/sec^2) $130 = 300.000 (X-axis maximum travel, millimeters) $131 = 300.000 (Y-axis maximum travel, millimeters) $132 = 50.000 (Z-axis maximum travel, millimeters)
Step 20: Calculate your steps/mm
For the steps per mm you need to calculate your own values. The formula is as follows: 360 : step angle : T8 thread pitch * your microsteps setting. For example, my stepper motor has a step angle of

1.8 degrees, my T8 screw has an 8mm thread pitch and I set the shield to 1/16 of a step, so putting that together it's 360:1.8:8*16 which comes out to 400.
After that, put the Arduino into the CNC shield.

# Raspberry Pi and Software Setup

Step 21: Flash and configure the Raspberry Pi
Next you’ll take care of the Raspberry Pi Zero W. Flash the SD card with the newest Raspberry Pi OS Lite image (make sure to set up automatic WiFi connection), boot it up, and SSH into it, then update the system, install Python 3.14 and pip. Then over FTP or SCP transfer the requirement.txt and rpi.py file onto the Pi, install the needed libraries using pip, and set the OS so that rpi.py launches on startup.
Step 22: Set up the control software on your PC
Next, on the support PC (the one that will be connected to LPODRO), also install libraries using pip, install pcb2gcode and launch the main.py file. During the first boot you’ll get a warning about a missing config. Press enter, a new config file has been created automatically and has everything you’ll need with default values that are a good starting point. Next you need to configure the connection with the Arduino Nano and the cameras, just press 4 in the main menu and connect to everything. When you’re finished, quit the app and relaunch it, check if the connection settings saved and when you press yes to reconnect check if the script connected with the Raspberry Pi (the PC needs to be on the same network as the Rpi!).
Step 23: Mark the bed
With the control software set up you can now preciselly move the machine around using UGS. With that you can precisely move the camera (you can go back to that step right now) and more importantly mark the bed. This is later used by the python program to detect the exact location of stuff placed on the bed. To mark the bed, home the machine and manually move it in such a way that the tip of the mill will be at the bottom left corner of the bed. This is your 0,0 point. Now move to 0,0 0,194 194,194 and 194,0 and at each of those posistions mill a small hole in the bed. With that done clean them of any debrie and put a small amount of paint in there. I used some nail paint.

# You're Done

If it does, congrats! You have a fully assembled and configured LPODRO machine that can be used to make PCBs! Now it is probably best to head to the user manual and try making your first PCB!

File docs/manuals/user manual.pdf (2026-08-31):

In this stage this file is very short. In the future I will turn it into a proper user manual explaining the software and how to use it in great detail. As of right now the software is just not ready for that. Right now you are reading an instruction that will just get you to mill your first pcbs.

If you properly finished the assembly guide when launching the python program you should be in the main menu and the program should be connected to the machine and two cameras.

As of right now even I don’t use the full capabilities of the python software I wrote for this machine. I use it to generate gcode but I send it to the machine using Universal Gcode Sender. The PnP function of the python program sorta works most of the time but it still in a very early stage. I have a few ideas how to greatly improve it in the future and I’m actively working on it.

As of right now the workflow for making 1 layer PCBs is as follows:
Generate gerber files in your cad software
If they are in a zip format extract it
Launch the python program and get to the main menu
Press the option 1
Choose the proper gerber files you want to mill (top layer, holes, vias, cutout etc.)
Save the generated files
Either quit the program and send those files to the machine using UGS or continue using the python script

No matter what option for sending the gcode files you choose you still need to mount the pcb to the bed somehow. To do so take the pcb holders, and put one on at least each corner of the pcb, then tighten the screw so that it holds it down. Then add one additional holder and in between it and the pcb put the pcb probe so that when the mill with the clamp touches it during autoleveling it will close the circuit. Also right before milling you need to put some sort of coolant on the pcb. I use WD40. Reapply it while the machine is milling if you see it has dried up. Also before your first run, keep a hand near the power switch and watch the first pass closely - a wrong Z-zero or bad autolevel can crash the bit into the bed.

If you choose to use UGS to send the gcode files you need to manually move the machine to the point 0 and reset the xyz coordinates to 0, probe the z level and do the autoleveling.

If you choose to use the python program instead make sure you calibrated everything correctly (option 3 from the main menu). If you did the program should automatically detect where the pcb is on the bed, move there, probe the Z height and do the autoleveling. Then it will mill the pcb. If you follow the instructions on the screen you should end up with a properly milled pcb.

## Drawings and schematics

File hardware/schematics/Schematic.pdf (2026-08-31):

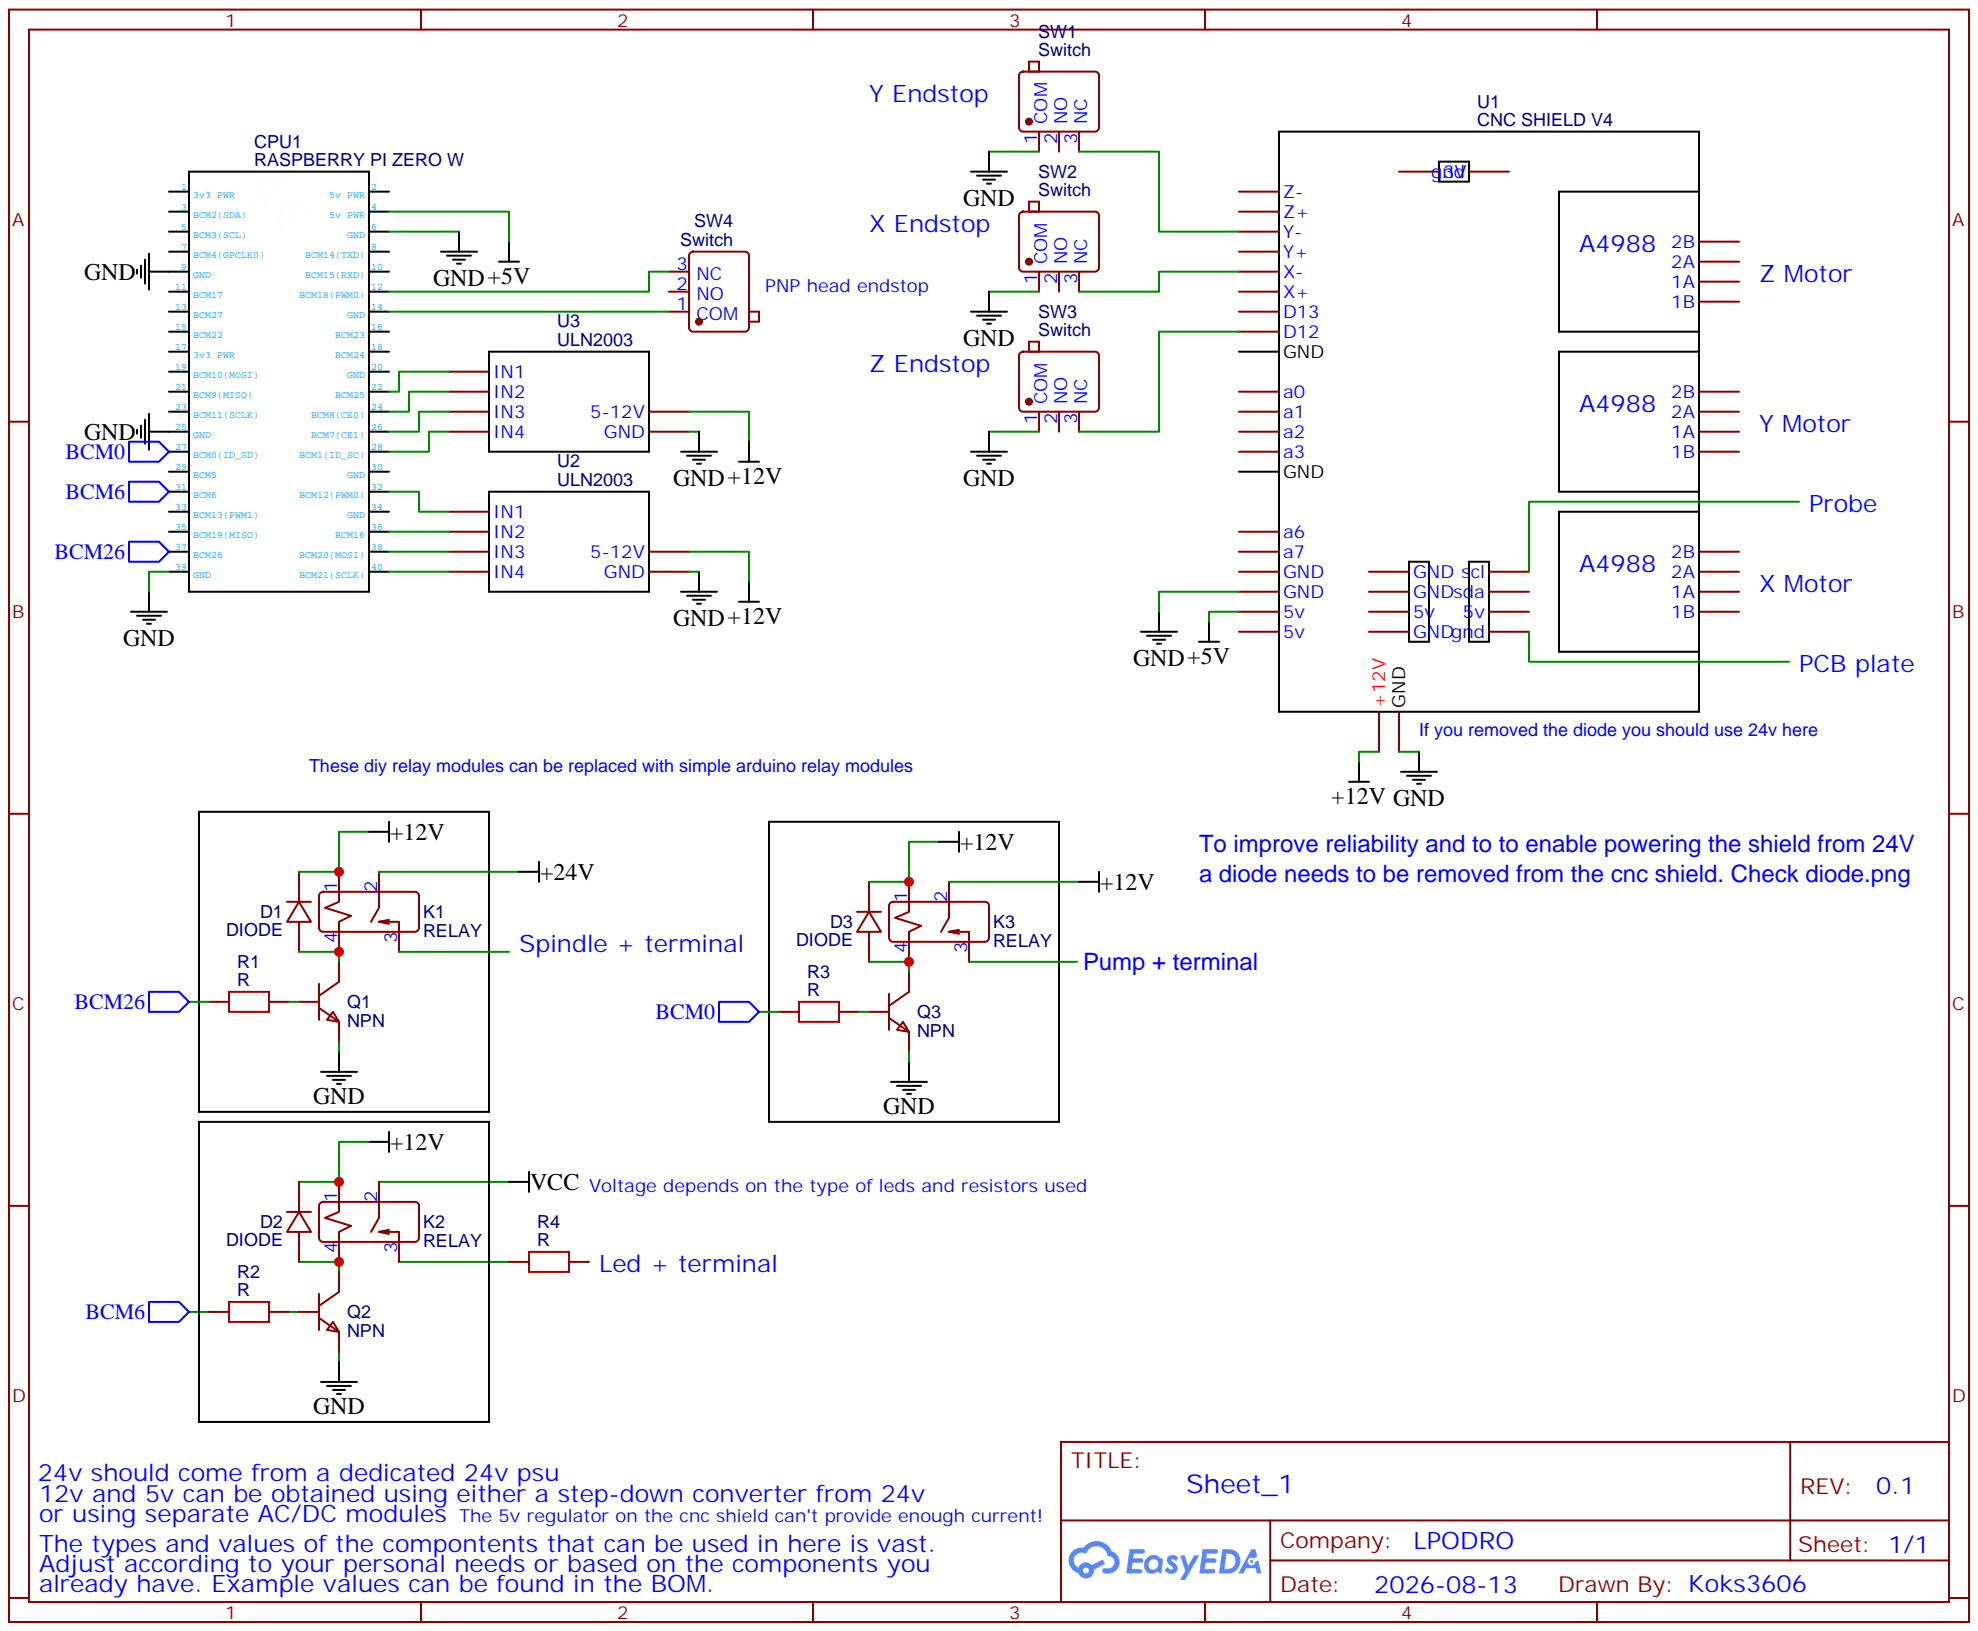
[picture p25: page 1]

If you removed the diode you should use 24v here

These diy relay modules can be replaced with simple arduino relay modules

To improve reliability and to to enable powering the shield from 24V
a diode needs to be removed from the cnc shield. Check diode.png

VCC Voltage depends on the type of leds and resistors used
Led + terminal

24v should come from a dedicated 24v psu
12v and 5v can be obtained using either a step-down converter from 24v
or using separate AC/DC modules
The types and values of the compontents that can be used in here is vast.
Adjust according to your personal needs or based on the components you
already have. Example values can be found in the BOM.

The 5v regulator on the cnc shield can't provide enough current!

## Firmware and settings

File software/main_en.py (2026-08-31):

from __future__ import annotations
import os
import readchar
import configparser
import subprocess
import glob
import time
import tkinter as tk
from tkinter import filedialog
import cv2
import numpy as np
import matplotlib.pyplot as plt
import json
import serial
from threading import Event
import serial.tools.list_ports
import sys
import re
import argparse
import csv
from scipy.interpolate import griddata
import math
import io
from collections import deque
import socket
import threading
import uuid
from typing import Dict, Optional, Tuple
from zeroconf import ServiceBrowser, ServiceListener, Zeroconf

xa = 0
ya = 0
x = 0
y = 0
polaczenie = 0
Z_RR=0.0

root = tk.Tk()
root.withdraw()

CONFIG_FILE = "config.ini"
CALIBRATION_FILE = 'homography.npy'
CALIBRATION_FILE_UP = 'homography_up.npy'
COLOR_CALIBRATION_FILE = 'color_params.json'

# Bazowe polecenie
cmd = ["pcb2gcode"]
vias = ["pcb2gcode"]

# Lista plików do wyboru
pliki = ["Górna warstwa", "Dolna warstwa", "outline", "vias", "through holes"]
sciezki = {}  # Słownik do przechowywania ścieżek

home = [
    "$H",
    "G92 X-16.4 Y-18.2 Z0"
]

home_z = [
    "$HZ"
]

gcode_zdj = [
    "G90 G0 Y192 X72.6"
]

unlock = [
    "$X"
]

cfg = configparser.ConfigParser()
if os.path.exists(CONFIG_FILE):
    cfg.read(CONFIG_FILE)
    if "Connection" not in cfg:
        raise RuntimeError("There is no [Connection] section in config.ini even though the file exists. It is most likely corrupted.")
    conn = cfg["Connection"]
    try:
        pnp_cam_x = float(conn.get("camera_up_x_mm"))
        pnp_cam_y = float(conn.get("camera_up_y_mm"))
    except Exception:
        raise RuntimeError("Camera_up_x_mm / camera_up_y_mm is missing in the [Connection] section even though the config.ini file exists. It is most likely corrupted.")

    pnp_cam_x = pnp_cam_x + float(conn.get("pnp_offset_x_mm"))
    pnp_cam_y = pnp_cam_y + float(conn.get("pnp_offset_y_mm"))
    gcode_zdj_up = [f"G90 G0 X{pnp_cam_x} Y{pnp_cam_y}"]
else:
    cfg["Settings"] = {
        "tool_diam": "0.1643",
        "multi_depth": "0.5",
        "passes": "1",
        "cut_z": "0.12",
        "pass_overlap": "10",
        "spindle": "0",
        "end_move": "2",
        "xyfeedrate": "120",
        "zfeedrate": "20",
        "travel_z": "2",
        "zdrill": "1.6",
        "milldrill_diameter": "1.5",
        "zcut_outline": "1.4",
        "outline_xyfeedrate": "70",
        "bridges": "4",
        "bridgesnum": "0",
        "zbridges": "1",
        "delta": "5",
        "zlevelmax": "0.15",
        "zlevelmin": "-3",
        "levelfeed": "10"
    }
    cfg["Connection"] = {
        "camera_up_x_mm": "123.2",
        "camera_up_y_mm": "176.1",
        "camera_rotation_deg": "0",
        "camera_up_rotation_deg": "0",
        "camera_ip": "",
        "camera_up_source": "",
        "serial_port": "",
        "pnp_offset_x_mm": "-9",
        "pnp_offset_y_mm": "40",
        "camera_up_corners": "127.6,179.4;127.6,176.4;122,176.4;122,179.4"
    }
    with open(CONFIG_FILE, "w") as config:
        cfg.write(config)
    print("THE CONFIGURATION FILE config.ini WAS NOT FOUND (it was deleted or corrupted)! A new one has been created with default values. PLEASE IMMEDIATELY PERFORM INITIAL CONFIGURATION BY SELECTING OPTION 2 ON THE NEXT SCREEN AND THEN RESTART THE PROGRAM!")
    input()



BAUD_RATE = 115200


SERVICE_TYPE = "_p2psignal._tcp.local."
DEFAULT_DISCOVERY_PORT = 50000
CONNECT_TIMEOUT_SECONDS = 3.0
HEARTBEAT_INTERVAL_SECONDS = 2.0
STALE_PONG_SECONDS = 6.0
DISCOVERY_RETRY_SECONDS = 2.0

_lock = threading.Lock()
_running = False
_zc: Optional[Zeroconf] = None
_browser: Optional[ServiceBrowser] = None
_discovery_thread: Optional[threading.Thread] = None
_recv_thread: Optional[threading.Thread] = None
_heartbeat_thread: Optional[threading.Thread] = None

_node_id = uuid.uuid4().hex[:12]
_display_name = socket.gethostname()
_peer_info: Optional[Tuple[str, int, str, str]] = None  # (peer_id, host, port, peer_name)
_sock: Optional[socket.socket] = None
_sock_lock = threading.Lock()
_last_pong = 0.0
_last_error: Optional[str] = None

_response_event = threading.Event()
_response_lock = threading.Lock()
_last_response = None
_pending_command = None

def _local_ipv4() -> str:
    s = socket.socket(socket.AF_INET, socket.SOCK_DGRAM)
    try:
        s.connect(("192.0.2.1", 1))
        return s.getsockname()[0]
    except OSError:
        try:
            return socket.gethostbyname(socket.gethostname())
        except OSError:
            return "127.0.0.1"
    finally:
        s.close()


def _drop_socket(sock: Optional[socket.socket]) -> None:
    if sock is None:
        return
    try:
        sock.shutdown(socket.SHUT_RDWR)
    except OSError:
        pass
    try:
        sock.close()
    except OSError:
        pass


def _set_disconnected(reason: str = "") -> None:
    global _sock, _last_error
    with _sock_lock:
        old = _sock
        _sock = None
        _last_error = reason or _last_error
    _drop_socket(old)


class _ReceiverDiscovery(ServiceListener):
    def add_service(self, zc: Zeroconf, type_: str, name: str) -> None:
        if not _running:
            return
        try:
            info = zc.get_service_info(type_, name, timeout=2000)
        except Exception:
            return
        if info is None:
            return

        props = info.properties or {}
        peer_id = props.get(b"id", b"").decode("utf-8", errors="ignore")
        peer_name = props.get(b"name", b"receiver").decode("utf-8", errors="ignore")
        if not peer_id or peer_id == _node_id:
            return

        host = next((addr for addr in info.parsed_addresses() if "." in addr), None)
        if host is None:
            return

        global _peer_info
        with _lock:
            _peer_info = (peer_id, host, int(info.port), peer_name)

    def remove_service(self, zc: Zeroconf, type_: str, name: str) -> None:
        # If the receiver disappears, the TCP connection will be dropped by the heartbeat.
        pass

    def update_service(self, zc: Zeroconf, type_: str, name: str) -> None:
        self.add_service(zc, type_, name)


def start_sender(display_name: Optional[str] = None, service_type: str = SERVICE_TYPE) -> None:
    """Start discovery and auto-connect to the first discovered receiver."""
    global _running, _zc, _browser, _discovery_thread, _recv_thread, _heartbeat_thread, _display_name, _last_error

    if _running:
        return

    _display_name = display_name or socket.gethostname()
    _running = True
    _last_error = None

    # Zeroconf browser that discovers the receiver.
    _zc = Zeroconf()
    _browser = ServiceBrowser(_zc, service_type, _ReceiverDiscovery())

    _discovery_thread = threading.Thread(target=_discovery_loop, daemon=True)
    _discovery_thread.start()

    _heartbeat_thread = threading.Thread(target=_heartbeat_loop, daemon=True)
    _heartbeat_thread.start()

    #print(f"[sender] node_id={_node_id}")
    #print(f"[sender] name={_display_name}")
    #print("[sender] waiting for receiver discovery...")


def stop_sender() -> None:
    """Stop background threads and close the TCP connection."""
    global _running, _zc
    _running = False
    _set_disconnected("stopped")

    try:
        if _zc is not None:
            _zc.close()
    except Exception:
        pass
    _zc = None


def _discovery_loop() -> None:
    while _running:
        if _sock is None:
            with _lock:
                peer = _peer_info
            if peer is not None:
                peer_id, host, port, peer_name = peer
                if _connect_to_peer(peer_id, host, port, peer_name):
                    # connection established
                    pass
        time.sleep(DISCOVERY_RETRY_SECONDS)


def _connect_to_peer(peer_id: str, host: str, port: int, peer_name: str) -> bool:
    global _sock, _last_pong, _last_error, _recv_thread
    with _sock_lock:
        if _sock is not None:
            return True

        sock = socket.socket(socket.AF_INET, socket.SOCK_STREAM)
        sock.settimeout(CONNECT_TIMEOUT_SECONDS)
        try:
            sock.connect((host, port))
            sock.settimeout(None)  # keep idle connections alive
            _sock = sock
            _last_pong = time.monotonic()
            _last_error = None
        except Exception as exc:
            _last_error = str(exc)
            try:
                sock.close()
            except OSError:
                pass
            return False

    _recv_thread = threading.Thread(
        target=_recv_loop, args=(sock, peer_id, host, port, peer_name), daemon=True
    )
    _recv_thread.start()
    #print(f"[sender] connected to {peer_name} ({peer_id}) at {host}:{port}")
    return True


def _recv_loop(sock: socket.socket, peer_id: str, host: str, port: int, peer_name: str) -> None:
    global _last_pong, _last_error, _last_response, _pending_command
    try:
        file = sock.makefile("r", encoding="utf-8", newline="\n")
        while _running:
            line = file.readline()
            if not line:
                break

            try:
                msg = json.loads(line)
            except json.JSONDecodeError:
                # Ignore malformed or legacy lines.
                continue

            msg_type = msg.get("type")
            if msg_type in ("pong"):
                _last_pong = time.monotonic()
            elif msg_type == "ack":
                _last_pong = time.monotonic()
            elif msg_type in ("accepted", "progress"):
                None
            elif msg_type in ("done", "error"):
                with _response_lock:
                    _last_response = msg
                _response_event.set()
            else:
                # Receiver may optionally send application messages back.
                print(f"[sender] rx from {peer_name}: {msg}")
    except Exception as exc:
        _last_error = f"recv error: {exc}"
    finally:
        print(f"[sender] disconnected from {peer_name} ({peer_id})")
        _set_disconnected("recv loop ended")


def _heartbeat_loop() -> None:
    while _running:
        time.sleep(HEARTBEAT_INTERVAL_SECONDS)

        if not is_connected():
            continue

        try:
            _send_json({"type": "ping", "ts": time.time()})
        except Exception:
            _set_disconnected("heartbeat failed")


def _send_json(payload: dict) -> None:
    sock = _sock
    if sock is None:
        raise ConnectionError("not connected")

    data = (json.dumps(payload, ensure_ascii=False) + "\n").encode("utf-8")
    with _sock_lock:
        sock.sendall(data)


def send_message(text: str, timeout: float = 30.0):
    """Send a command and block until receiver replies with done/error.

    Returns the final response dict on success.
    Raises RuntimeError on receiver error.
    Raises TimeoutError if no final response arrives in time.
    """
    if not is_connected():
        raise ConnectionError("not connected")

    global _pending_command, _last_response
    with _response_lock:
        _pending_command = text
        _last_response = None
        _response_event.clear()

    try:
        _send_json({"type": "msg", "payload": text})
    except Exception:
        _set_disconnected("send failed")
        raise

    if not _response_event.wait(timeout):
        raise TimeoutError(f"no done/error response for command: {text}")

    with _response_lock:
        resp = _last_response

    if not resp:
        raise RuntimeError("response event set, but no response stored")

    if resp.get("type") == "error":
        raise RuntimeError(resp.get("error", "receiver returned error"))

    return resp

def is_connected() -> bool:
    """Best-effort connection state.

    Returns True only when:
      - a TCP socket exists,
      - the socket still looks open,
      - and the last PONG arrived recently.
    """
    sock = _sock
    if sock is None:
        return False

    try:
        sock.getpeername()
    except OSError:
        return False

    if (time.monotonic() - _last_pong) > STALE_PONG_SECONDS:
        return False
    return True


def peers_snapshot() -> Dict[str, Tuple[str, int, str]]:
    """Return the last discovered receiver info for debugging."""
    with _lock:
        peer = _peer_info
    if peer is None:
        return {}
    peer_id, host, port, peer_name = peer
    return {peer_id: (host, port, peer_name)}


def last_error() -> Optional[str]:
    return _last_error

def format_value(value):
    """Formatuje wartość: bez '.0' dla liczb całkowitych, z kropką dla ułamkowych."""
    return str(int(value)) if value == int(value) else str(value)

def save_millproject(config):
    millproject_content = f"""
# Pcb2GCode settings
metric=true
metricoutput=true
zero-start=true
zsafe={format_value(config['travel_z'])}
zchange=5
software=custom
mirror-axis=1

# Milling - Trace engraving
mill-vertfeed=20
zwork=-{format_value(config['cut_z'])}mm
mill-feed={format_value(config['xyfeedrate'])}
mill-speed={format_value(config['spindle'])}
mill-diameters={format_value(config['tool_diam'])}mm
isolation-width=0.55mm
milling-overlap={format_value(config['pass_overlap'])}%

# Drilling
zdrill=-{format_value(config['zdrill'])}
zmilldrill=-{format_value(config['zdrill'])}
drill-side=back
drill-feed={format_value(config['zfeedrate'])}
drill-speed={format_value(config['spindle'])}
drills-available=0.3mm,0.4mm,0.5mm,0.6mm,0.7mm,0.8mm,0.9mm
milldrill-diameter={format_value(config['milldrill_diameter'])}mm
min-milldrill-hole-diameter={format_value(config['milldrill_diameter'])}mm

# Outline
zcut=-{format_value(config['zcut_outline'])}
cut-side=back
cut-feed={format_value(config['outline_xyfeedrate'])}
cut-vertfeed={format_value(config['zfeedrate'])}
cut-speed={format_value(config['spindle'])}
cut-infeed={format_value(config['multi_depth'])}
cutter-diameter={format_value(config['milldrill_diameter'])}mm
bridges={format_value(config['bridges'])}
bridgesnum={format_value(config['bridgesnum'])}
zbridges=-{format_value(config['zbridges'])}

# GRBL shenanigans
nog64=true
nog81=true
nog91-1=true
"""
    return millproject_content

def cls():
    os.system('cls' if os.name == 'nt' else 'clear')

def manual_calibration(img_bgr, real_coords=None):
    """
    Ręczna kalibracja homografii: klik 4 punkty kalibracyjne.
    img_bgr: obraz w przestrzeni BGR (numpy.ndarray)
    real_coords: lista 4 krotek (X,Y) w docelowej przestrzeni.
    Zapisuje macierz H do pliku.
    """
    if real_coords is None:
        real_coords = [(0, 0), (0, 194), (194, 194), (194, 0)]

    if img_bgr is None:
        raise ValueError("The provided image is empty (None).")

    img_rgb = cv2.cvtColor(img_bgr, cv2.COLOR_BGR2RGB)
    fig, ax = plt.subplots(figsize=(8, 6))
    ax.imshow(img_rgb)
    ax.set_title('Click the following in order: (0, 0), (0, 194), (194, 194), (194, 0)')
    pts = []

    def onclick(event):
        if event.xdata is None or event.ydata is None:
            return
        pts.append([event.xdata, event.ydata])
        ax.plot(event.xdata, event.ydata, 'rx', markersize=5)
        fig.canvas.draw()
        if len(pts) == 4:
            plt.close(fig)

    fig.canvas.mpl_connect('button_press_event', onclick)
    plt.show()

    if len(pts) != 4:
        print(f"Calibration interrupted; only {len(pts)} points found.")
        return

    src = np.array(pts, dtype=np.float32)
    dst = np.array(real_coords, dtype=np.float32)
    H = cv2.getPerspectiveTransform(src, dst)
    np.save(CALIBRATION_FILE, H)
    print(f"Saved the homography matrix in {CALIBRATION_FILE}")

def manual_color_calibration(img_bgr):
    """
    Ręczna kalibracja koloru: klik punkty na laminacie.
    img_bgr: obraz w przestrzeni BGR (numpy.ndarray)
    Zapisuje parametry koloru do JSON.
    """
    if img_bgr is None:
        raise ValueError("The provided image is empty (None).")

    img_rgb = cv2.cvtColor(img_bgr, cv2.COLOR_BGR2RGB)
    img_hsv = cv2.cvtColor(img_bgr, cv2.COLOR_BGR2HSV)

    fig, ax = plt.subplots(figsize=(8, 6))
    ax.imshow(img_rgb)
    ax.set_title('Click on the laminate, then close the window when finished.')
    samples = []

    def onclick(event):
        if event.xdata is None or event.ydata is None:
            return
        x, y = int(event.xdata), int(event.ydata)
        samples.append(img_hsv[y, x])
        ax.plot(x, y, 'bo', markersize=5)
        fig.canvas.draw()

    fig.canvas.mpl_connect('button_press_event', onclick)
    plt.show()

    if not samples:
        print("No color samples. Calibration interrupted.")
        return

    arr = np.array(samples, dtype=np.float32)
    H0, S0, V0 = arr.mean(axis=0)
    dH, dS, dV = 15, 50, 50
    lower = [int(max(0, H0 - dH)), int(max(0, S0 - dS)), int(max(0, V0 - dV))]
    upper = [int(min(179, H0 + dH)), int(min(255, S0 + dS)), int(min(255, V0 + dV))]

    with open(COLOR_CALIBRATION_FILE, 'w') as f:
        json.dump({'lower': lower, 'upper': upper}, f, indent=2)
    print(f"Color parameters saved in {COLOR_CALIBRATION_FILE}")

def load_homography(camera='top'):
    """
    Zwraca macierz H (image -> machine mm) dla 'top' lub 'up'.
    'top' używa istniejącego CALIBRATION_FILE, 'up' używa CALIBRATION_FILE_UP.
    Rzuca FileNotFoundError jeśli brak pliku.
    """
    if camera == 'top':
        if not os.path.isfile(CALIBRATION_FILE):
            raise FileNotFoundError("No homography. Perform homography calibration.")
        return np.load(CALIBRATION_FILE)
    elif camera == 'up':
        if not os.path.isfile(CALIBRATION_FILE_UP):
            raise FileNotFoundError("No homography for the 'up' camera. Perform calibration (manual_calibration_up).")
        return np.load(CALIBRATION_FILE_UP)
    else:
        raise ValueError("camera must be 'top' or 'up'")
    
def pixel_to_machine_using_homography(px, py, camera='up'):
    """
    px,py - pixel coords (x=col,y=row) w obrazie danej kamery.
    Dla 'top' używa load_homography(), dla 'up' load_homography_for('up').
    Zwraca (X_mm, Y_mm).
    """
    H = load_homography(camera)
    p = np.array([[[float(px), float(py)]]], dtype=np.float32)
    mm = cv2.perspectiveTransform(p, H)[0][0]
    return float(mm[0]), float(mm[1])

def load_color_params():
    if not os.path.isfile(COLOR_CALIBRATION_FILE):
        raise FileNotFoundError("Color calibration missing. Perform color calibration.")
    data = json.load(open(COLOR_CALIBRATION_FILE))
    return np.array(data['lower'], dtype=np.uint8), np.array(data['upper'], dtype=np.uint8)

def detect_copper_corner(img_bgr):
    """
    Wykrywa róg laminatu bez używania ścieżki pliku.
    img_bgr: obraz w przestrzeni BGR (numpy.ndarray)
    Zwraca:
      X, Y – współrzędne rogu po transformacji projekcyjnej
    """
    # Załaduj parametry tylko raz, jeżeli nie zostały przekazane
    H = load_homography()
    lower, upper = load_color_params()

    if img_bgr is None:
        raise ValueError("The provided image is empty (None).")

    # Konwersja na RGB i HSV
    img_rgb = cv2.cvtColor(img_bgr, cv2.COLOR_BGR2RGB)
    img_hsv = cv2.cvtColor(img_bgr, cv2.COLOR_BGR2HSV)

    # 1) Oryginał
    plt.figure(figsize=(6,6))
    plt.imshow(img_rgb)
    plt.title('1) Original photo')
    plt.axis('off')
    plt.show()

    # 2) Maska koloru
    mask = cv2.inRange(img_hsv, lower, upper)
    kernel = cv2.getStructuringElement(cv2.MORPH_ELLIPSE, (15, 15))
    mask = cv2.morphologyEx(mask, cv2.MORPH_CLOSE, kernel)

    plt.figure(figsize=(6,6))
    plt.imshow(mask, cmap='gray')
    plt.title('2) Laminate color mask')
    plt.axis('off')
    plt.show()
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

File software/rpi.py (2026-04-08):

from __future__ import annotations

import RPi.GPIO as GPIO
import math
import time
import json
import signal
import socket
import threading
import time
import uuid
from typing import Callable, Optional, Tuple

from zeroconf import ServiceInfo, ServiceListener, Zeroconf

SERVICE_TYPE = "_p2psignal._tcp.local."
DEFAULT_PORT = 50000
HANDSHAKE_FREE = True  # kept for readability; protocol is line-based JSON.

running = threading.Event()
running.set()

zc = Zeroconf()
node_id = uuid.uuid4().hex[:12]
display_name = socket.gethostname()
server_socket: Optional[socket.socket] = None


motor1_pins = [24, 25, 8, 7]
motor2_pins = [12, 16, 20, 21]

dremel_pin = 26
pump_pin = 0

GPIO.setmode(GPIO.BCM)
GPIO.setwarnings(False)

GPIO.setup(pump_pin, GPIO.OUT)
GPIO.output(pump_pin, GPIO.LOW)
GPIO.setup(dremel_pin, GPIO.OUT)
GPIO.output(dremel_pin, GPIO.LOW)

for pin in motor2_pins:
    GPIO.setup(pin, GPIO.OUT)
    GPIO.output(pin, GPIO.LOW)

for pin in motor1_pins:
    GPIO.setup(pin, GPIO.OUT)
    GPIO.output(pin, GPIO.LOW)
GPIO.setup(18, GPIO.IN, GPIO.PUD_UP)

sequence = [
    [1, 0, 0, 0],
    [1, 1, 0, 0],
    [0, 1, 0, 0],
    [0, 1, 1, 0],
    [0, 0, 1, 0],
    [0, 0, 1, 1],
    [0, 0, 0, 1],
    [1, 0, 0, 1],
]

STEPS_PER_REV = 4096  # punkt startowy dla 28BYJ-48
STEPS_PER_MM = 86

def local_ipv4() -> str:
    s = socket.socket(socket.AF_INET, socket.SOCK_DGRAM)
    try:
        s.connect(("192.0.2.1", 1))
        return s.getsockname()[0]
    except OSError:
        try:
            return socket.gethostbyname(socket.gethostname())
        except OSError:
            return "127.0.0.1"
    finally:
        s.close()


def handle_message(peer_addr: Tuple[str, int], message: str, conn: socket.socket) -> None:
    """Example reaction. Replace this with your own logic."""
    print(f"[app] from {peer_addr}: {message}")

    if message == "START":
        print("[app] received START -> do something here")
    elif message == "PUMP_ON":
        GPIO.output(pump_pin, GPIO.HIGH)
    elif message == "PUMP_OFF":
        GPIO.output(pump_pin, GPIO.LOW)
    elif message == "DREMEL_ON":
        GPIO.output(dremel_pin, GPIO.HIGH)
    elif message == "DREMEL_OFF":
        GPIO.output(dremel_pin, GPIO.LOW)
    elif message.startswith("ALARM:"):
        level = message.split(":", 1)[1]
        print(f"[app] alarm level = {level}")
    elif message.startswith("SPIN:"):
        angle = float(message.split(":", 1)[1])
        print(f"[app] rotate motor2 {angle}")
        if angle > 0:
            direction=-1
        else:
            direction = 1
            angle = angle * -1
        angle = angle * 2.2
        rotate_degrees(angle, motor_pins=motor2_pins, direction=direction, delay=0.0005)
    elif message.startswith("GO:"):
        distance = message.split(":", 1)[1]
        distance = int(float(distance))
        if distance > 0:
            direction=-1
        else:
            direction = 1
            distance = distance * -1
        steps = distance * STEPS_PER_MM
        steps = int(math.ceil(steps))
        rotate(steps=steps, direction=direction)
    elif message == "STOP":
        print("[app] received STOP -> stop your action here")
    elif message == "HOME":
        result = home()
        send_lock = threading.Lock()
        send_json(conn, send_lock, {
            "type": "done",
            "command": "HOME",
            "ok": True,
            "data": {"home_distance": result}
        })
    else:
        print("[app] generic command processed")


def advertise() -> None:
    ip = local_ipv4()
    info = ServiceInfo(
        SERVICE_TYPE,
        f"{display_name}-{node_id}.{SERVICE_TYPE}",
        addresses=[socket.inet_aton(ip)],
        port=server_socket.getsockname()[1] if server_socket else DEFAULT_PORT,
        properties={
            b"id": node_id.encode("utf-8"),
            b"name": display_name.encode("utf-8"),
        },
        server=f"{socket.gethostname()}.local.",
    )
    zc.register_service(info)
    return info


def start_server(port: int = DEFAULT_PORT) -> None:
    global server_socket
    sock = socket.socket(socket.AF_INET, socket.SOCK_STREAM)
    sock.setsockopt(socket.SOL_SOCKET, socket.SO_REUSEADDR, 1)
    sock.bind(("", port))
    sock.listen(5)
    sock.settimeout(1.0)
    server_socket = sock


def stop() -> None:
    running.clear()
    try:
        if server_socket is not None:
            server_socket.close()
    except OSError:
        pass
    try:
        zc.close()
    except Exception:
        pass


def client_loop(conn: socket.socket, addr: Tuple[str, int]) -> None:
    send_lock = threading.Lock()
    try:
        file = conn.makefile("r", encoding="utf-8", newline="\n")
        while running.is_set():
            line = file.readline()
            if not line:
                break

            try:
                msg = json.loads(line)
            except json.JSONDecodeError:
                continue

            msg_type = msg.get("type")

            if msg_type == "ping":
                send_json(conn, send_lock, {"type": "pong"})
                continue

            if msg_type == "msg":
                payload = str(msg.get("payload", ""))

                send_json(conn, send_lock, {"type": "accepted", "command": payload})

                threading.Thread(
                    target=process_command,
                    args=(addr, payload, conn, send_lock),
                    daemon=True
                ).start()
                continue
    except Exception as exc:
        print(f"[rx] client error from {addr}: {exc}")
    finally:
        try:
            conn.close()
        except OSError:
            pass
        print(f"[rx] disconnected {addr}")


def server_loop() -> None:
    assert server_socket is not None
    while running.is_set():
        try:
            conn, addr = server_socket.accept()
        except socket.timeout:
            continue
        except OSError:
            break

        print(f"[rx] connected {addr}")
        threading.Thread(target=client_loop, args=(conn, addr), daemon=True).start()

def rotate_degrees(degrees, delay=0.002, direction=1, motor_pins=None):
    if motor_pins is None:
        motor_pins = motor1_pins

    steps = int(math.ceil(STEPS_PER_REV * degrees / 360.0))
    seq = sequence if direction == 1 else list(reversed(sequence))

    for i in range(steps):
        step = seq[i % len(seq)]
        for pin, value in zip(motor_pins, step):
            GPIO.output(pin, value)
        time.sleep(delay)
    for pin, value in zip(motor_pins, step):
        GPIO.output(pin, GPIO.LOW)
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

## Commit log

2026-04-08 Nowy README i pierwsze pliki projektu
    [Pilar osi X 1.stl, Pilar osi X 2.stl, Stół uchwyt nakrętki 1.stl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]
2026-08-31 New or improved 3D models, schematic, manuals, photos, slightly improved software, and a full switch to English. Preparations for the initial release.
    [BOM.xlsx, Gear 2.stl, Pilar osi X 1.stl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]

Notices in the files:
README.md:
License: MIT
